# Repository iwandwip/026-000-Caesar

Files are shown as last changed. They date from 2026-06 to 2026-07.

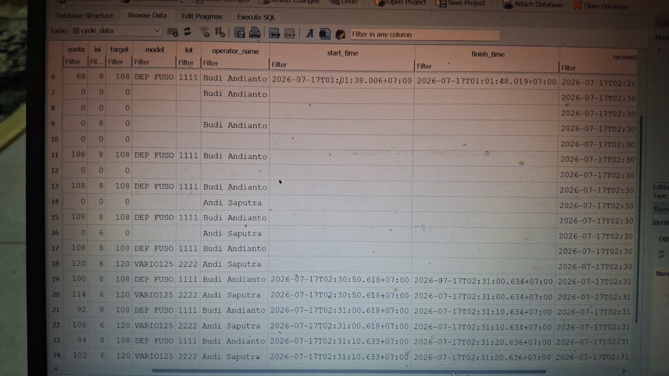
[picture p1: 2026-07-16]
docs/2.jpeg

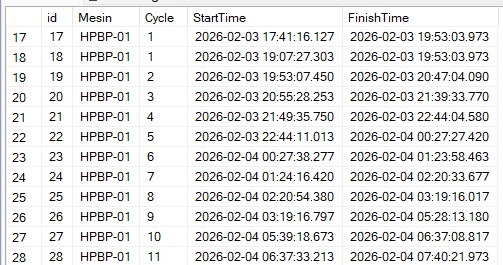
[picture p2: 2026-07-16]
docs/1.jpeg

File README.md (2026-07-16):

# Caesar Control System

Caesar is an ESP32 control project for a two-side production process. It combines a Nextion HMI, a GM66 barcode scanner, and a DS3231 RTC. The firmware owns validation and process state; the HMI presents data and sends user actions.

## Repository Layout

```text
026-000-Caesar/
├── firmware/                         ESP32 firmware, local Arduino libraries, and setup notes
│   ├── CaesarFirmwareV1/             Main Arduino sketch
│   └── README.md                     Firmware architecture, wiring, and HMI contract
├── HMI/                              Versioned Nextion .HMI source files
├── nextion/                          HMI file used by extractor and extracted source views
│   ├── HMI CAESAR_15.HMI             Current extraction input
│   ├── Nextion2Text/                 Nextion2Text checkout
│   └── output/                       Extracted text and JSON per HMI revision
├── src/                              HMI extraction scripts
├── pcb/                              PCB design archive and extracted design files
├── assets/                           Manual, work instruction, and reference documents
├── docs/                             Design specifications and implementation plans
└── README.md
```

`HMI/` stores HMI revision history. Copy the revision you want to inspect into `nextion/` before running the extractor. The current extractor input is `nextion/HMI CAESAR_15.HMI`.

## System Overview

| Component | Responsibility |
| --- | --- |
| ESP32 | Validates operators, moulds, lots, downtime state, scanner input, and RTC data. |
| Nextion HMI | Displays process state, accepts manual input, and sends page and button events. |
| GM66 scanner | Sends barcode data to ESP32 through `Serial2`. |
| DS3231 RTC | Supplies timestamps for `pageSys.tNow` and downtime start records. |

The firmware stores shared process state in `pageSys` on the HMI. Firmware callbacks validate process actions.

See [`firmware/README.md`](firmware/README.md) for wiring, firmware modules, supported input flows, and HMI integration requirements.

## Windows Setup

Use this sequence after cloning on a Windows laptop.

```powershell
git clone <repository-url>
cd 026-000-Caesar
npm install
```

Install Arduino IDE, add the ESP32 board package, then open `firmware/CaesarFirmwareV1/CaesarFirmwareV1.ino`. Install or expose the libraries under `firmware/libraries/` to your Arduino environment before compiling.

Set the WiFi network for the target site in `firmware/CaesarFirmwareV1/config.h`:

```cpp
#define WIFI_SSID "your-wifi-name"
#define WIFI_PASS "your-wifi-password"
```

The firmware and tools use HiveMQ public MQTT. Each deployed machine needs its own `MQTT_ADDR`. Update the same address in these files before running multiple machines:

```text
firmware/CaesarFirmwareV1/config.h
tools/mqtt-simulator.js
tools/mqtt-debug-subscriber.js
tools/node-red-simulator-flow.json
tools/node-red-debug-subscriber-flow.json
```

Flash the ESP32 after configuring WiFi and the address.

## MQTT Tools

Install Node.js LTS, then run `npm install` from repository root.

```powershell
# Terminal 1: simulated machine publishes START and finish events.
npm run mqtt:simulate

# Terminal 2: receives firmware dataA/dataB messages and writes SQLite rows.
npm run mqtt:debug
```

The simulator sends `START`, waits 10 seconds, then sends a `1cycle` event with `startTime` and `finishTime`. Firmware counts the event when both interlocks are ready. It publishes retained Front and Back state after each accepted cycle and process-state change.

`mqtt:debug` creates `data/caesar.db` in the repository. Set `CAESAR_DB_PATH` when you need another database location:

```powershell
$env:CAESAR_DB_PATH = "D:\CaesarData\caesar.db"
npm run mqtt:debug
```

Use [DB Browser for SQLite](https://sqlitebrowser.org/) to inspect table `cycle_data`.

### Node-RED Option

Use Node-RED instead of either JavaScript process when you want a visual flow.

```powershell
# Run once if node-red is not installed.
npm install -g --unsafe-perm node-red

# First run creates the Node-RED user directory.
node-red

# Stop Node-RED, then install the SQLite node.
cd $env:USERPROFILE\.node-red
npm install node-red-node-sqlite

# Create the shared SQLite directory once.
New-Item -ItemType Directory -Force C:\sqlite-data
```

Import `tools/node-red-simulator-flow.json` for the machine simulator. Import `tools/node-red-debug-subscriber-flow.json` for the subscriber and SQLite writer. Deploy both flows after import. The debug flow writes `C:\sqlite-data\caesar.db` for every Windows user. If Windows denies directory creation, create `C:\sqlite-data` once from an elevated PowerShell session.

Run one simulator only: JavaScript or Node-RED. Running both publishes duplicate finish events and doubles cycle counts.

## HMI Extraction

The extraction workflow converts a Nextion `.HMI` file into text and JSON for review, Git diffs, and firmware work. It only reads `.HMI` files. It cannot rebuild an `.HMI` file from extracted output.

### Requirements

- Linux shell or Bash
- Git
- Python 3.8 or newer
- A `.HMI` file directly inside `nextion/`

Check Python:

```bash
python3 --version
```

Create a virtual environment when needed:

```bash
python3 -m venv .venv
source .venv/bin/activate
```

The extraction scripts use Python standard-library modules only.

### Run Extraction

From repository root:

```bash
./src/nextion2text.sh
```

The script:

1. Finds `.HMI` and `.hmi` files directly under `nextion/`.
2. Clones [Nextion2Text](https://github.com/MMMZZZZ/Nextion2Text) into `nextion/Nextion2Text/` when absent.
3. Replaces previous output for each processed HMI file.
4. Writes text and JSON output to `nextion/output/<hmi-name>/`.

For `nextion/HMI CAESAR_15.HMI`, output appears under:

```text
nextion/output/HMI_CAESAR_15/
├── text/
└── json/
```

The script calls Nextion2Text with:

```bash
-e -s -j -p visual
```

| Flag | Purpose |
| --- | --- |
| `-e` | Includes empty events. |
| `-s` | Produces page, component, and event statistics. |
| `-j` | Produces JSON output. |
| `-p visual` | Includes visual properties such as coordinates, colors, fonts, and images. |

### Linux `ansi` Codec Error

Nextion2Text requests the Windows `ansi` codec. Linux Python does not provide that name. `src/run_nextion2text.py` registers `ansi` as `latin-1` before it starts Nextion2Text.

Run `./src/nextion2text.sh`; do not run `Nextion2Text.py` directly on Linux.

### Common Errors

`ERROR: no .HMI files found` means no `.HMI` file exists directly in `nextion/`. Copy the desired source file from `HMI/` first.

```bash
cp "HMI/HMI CAESAR_15.HMI" "nextion/HMI CAESAR_15.HMI"
./src/nextion2text.sh
```

If the script lacks execute permission:

```bash
chmod +x src/nextion2text.sh
```

## Project Documents

- `assets/MANUAL BOOK_CAESAR.docx`: Caesar manual.
- `assets/WORK INSTRUCTION_CAESAR.pdf`: work instruction.
- `assets/SKRIPSI_CAESAR.docx`: project thesis.
- `pcb/`: PCB source archive and extracted project files.

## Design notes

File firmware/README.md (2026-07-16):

# Caesar ESP32 Firmware

`CaesarFirmwareV1` runs on ESP32 and controls Nextion process state, a GM66 scanner, and a DS3231 RTC. The firmware validates all operator, mould, lot, and downtime actions. The HMI displays values and reports page or button events.

Open `firmware/CaesarFirmwareV1/CaesarFirmwareV1.ino` in Arduino IDE or your ESP32 Arduino build environment.

## Source Files

| File | Responsibility |
| --- | --- |
| `CaesarFirmwareV1.ino` | Page and component declarations, setup, main loop, and callback registration. |
| `config.h` | Serial settings and static operator, mould, and lot lookup tables. |
| `login.ino` | Front and back operator login, logout, and page tracking. |
| `input.ino` | Mould and lot input, validation, clearing, and raw Nextion value reads. |
| `scanner.ino` | GM66 receive buffer and page-specific scanner routing. |
| `downtime.ino` | Front, back, and machine downtime state transitions. |
| `rtc.ino` | DS3231 initialization and one-second HMI time updates. |
| `dashboard.ino` | Dashboard status, readiness, and interlock display synchronization. |
| `simulation.ino` | Front and back auto-cycle controls on `pageSim`. |
| `cycle.ino` | MQTT finish-event validation and Front/Back cycle mutation. |
| `wifi_mqtt.ino` | WiFi connection, MQTT reconnect, subscriptions, and command dispatch. |
| `publish.ino` | Retained MQTT JSON for Front and Back process state. |

## Dependencies

The repository includes local Arduino libraries under `firmware/libraries/`.

- ESP32 Arduino core
- ITEADLIB Arduino Nextion library
- Adafruit RTClib
- Adafruit BusIO
- ArduinoJson 7
- PubSubClient

Select the ESP32 board that matches the deployed hardware. The repository does not contain an Arduino CLI configuration or a pinned board package version.

## Wiring and Serial Ports

### Nextion HMI

The ITEAD library uses ESP32 `Serial` for Nextion traffic:

```cpp
// firmware/libraries/ITEADLIB_Arduino_Nextion/NexConfig.h
#define nexSerial Serial
```

Nextion Editor Debug and the deployed display share this serial channel. Do not open Arduino Serial Monitor on the same USB serial port while Nextion Editor Debug is connected. ITEAD debug output stays disabled because it would corrupt Nextion protocol frames.

### GM66 Scanner

`config.h` configures the scanner on ESP32 `Serial2`.

```cpp
#define SCANNER_SERIAL Serial2
#define SCANNER_RX_PIN 16
#define SCANNER_TX_PIN 17
#define SCANNER_BAUD 9600
```

| GM66 wire | ESP32 connection |
| --- | --- |
| TX | GPIO16, Serial2 RX |
| RX | GPIO17, Serial2 TX |
| VCC | 5V |
| GND | GND |

The scanner uses `9600`, `SERIAL_8N1`.

### DS3231 RTC

`rtc.ino` uses `Wire.begin()`, which uses ESP32 default I2C pins unless the board setup overrides them.

| DS3231 signal | Default ESP32 pin |
| --- | --- |
| SDA | GPIO21 |
| SCL | GPIO22 |

The firmware reads time once each second and writes `YYYY-MM-DD HH:MM:SS` to `pageSys.tNow.txt`. If the RTC lost power, firmware initializes it with compile time. Set the RTC to production time before deployment.

## Nextion Page IDs

Page IDs follow page order in Nextion Editor. Firmware declarations must match this mapping.

| ID | Page |
| --- | --- |
| 0 | `pageDashboard` |
| 1 | `pageLoginF` |
| 2 | `pageLoginB` |
| 3 | `pageMldF` |
| 4 | `pageMldB` |
| 5 | `pageLotF` |
| 6 | `pageLotB` |
| 7 | `pageOutputNG` |
| 8 | `pageInputNGF` |
| 9 | `pageInputNGB` |
| 10 | `pageDtF` |
| 11 | `pageDtB` |
| 12 | `pageDtInfoF` |
| 13 | `pageDtInfoB` |
| 14 | `pageDtMc` |
| 15 | `pageDtMcInfo` |
| 16 | `pageSim` |
| 17 | `pageSys` |
| 18 | `keybdA` |
| 19 | `keybdB` |

Each page sends a page notification through its Preinitialize event. Example for the dashboard:

```text
printh 65 00 00 00 FF FF FF
```

Use the page ID in the third byte. `pageCallback()` updates `currentPageId`, which controls where scanner data is written.

## Process Data

`config.h` contains the current static lookup tables.

| Code | Operator | Mould | Cavity | Lot model | Target |
| --- | --- | --- | ---: | --- | ---: |
| `1111` | Budi Andianto | MOULD A | 8 | DEP FUSO | 108 |
| `2222` | Andi Saputra | MOULD B | 6 | VARIO125 | 120 |
| `3333` | Siti Nurhaliza | MOULD C | 4 | GENIO | 96 |

Change these tables in `config.h` when production master data changes.

## WiFi and MQTT

Set site WiFi credentials and the machine address in `config.h` before flashing:

```cpp
#define WIFI_SSID "your-wifi-name"
#define WIFI_PASS "your-wifi-password"
#define MQTT_ADDR "unique-machine-address"
```

The current broker is `broker.hivemq.com:1883`. Each machine address must be unique on the public broker.

| Topic | Direction | Payload |
| --- | --- | --- |
| `start/IOTHP-BP/<addr>` | Simulator to server | `START` |
| `finish/IOTHP-BP/<addr>` | Simulator to ESP32 | JSON `1cycle` event with timestamps |
| `CONTROL/IOTHP-BP/<addr>` | Server to ESP32 | `REBOOT` |
| `dataA/IOTHP-BP/<addr>` | ESP32 to server | Retained Front state JSON |
| `dataB/IOTHP-BP/<addr>` | ESP32 to server | Retained Back state JSON |

The firmware accepts a finish event only when its payload has this shape:

```json
{
  "event": "1cycle",
  "startTime": "2026-07-16T07:00:00.000Z",
  "finishTime": "2026-07-16T07:00:10.000Z"
}
```

Firmware ignores the event when either side is not ready, quota cannot cover isi, or required HMI state cannot be read. A valid event increments both layer cycles, updates output and quota, then publishes retained state.

Each `dataA` and `dataB` message contains:

```json
{
  "cycle": 42,
  "output": 336,
  "ok": 330,
  "ng": 6,
  "quota": 72,
  "isi": 8,
  "target": 108,
  "model": "DEP FUSO",
  "lot": "1111",
  "operator": "Budi Andianto",
  "startTime": "2026-07-16T07:00:00.000Z",
  "finishTime": "2026-07-16T07:00:10.000Z"
}
```

Firmware also publishes after valid mould or lot changes, clears, login, and logout. These state-only messages keep the last accepted cycle timestamps.

See the root [MQTT tools section](../README.md#mqtt-tools) for JavaScript and Node-RED simulator, subscriber, and SQLite setup.

## Login Flow

1. Open `pageLoginF` or `pageLoginB`.
2. Scan an operator barcode or enter an ID manually.
3. Press OK.
4. Firmware validates `OPERATORS[]`, writes the operator data to `pageSys`, and displays the operator name.

Invalid IDs display `ID SALAH`.

## Mould and Lot Flow

Scanner and manual keyboard input follow the same model: fill a field, then press OK. Firmware owns the validation and save action.

### Mould

On `pageMldF` and `pageMldB`, a valid code writes the mould code, model, cavity, and default isi values to `pageSys`. Firmware also initializes `pageLotF.nIsiLotF` or `pageLotB.nIsiLotB` from the cavity count.

### Lot

On `pageLotF` and `pageLotB`, a valid lot requires a mould on the same side. Firmware reads cavity and isi through raw Nextion number responses, then rejects these conditions:

| Condition | HMI message |
| --- | --- |
| Unknown lot code | `LOT NG` |
| Cavity read failure | `CAV READ NG` |
| Isi read failure | `ISI READ NG` |
| No validated mould | `NO MOULD` |
| Isi is zero | `ISI 0` |
| Isi exceeds cavity | `ISI > CAV` |

Keyboard edits to lot isi remain in the lot page. Returning from a keyboard page does not overwrite the value.

`readNextionText()` and `readNextionValue()` in `input.ino` read `0x70` text and `0x71` numeric response frames directly. They avoid the ITEAD library response parser when delayed serial frames would produce an empty or stale result.

## Scanner Routing

Scanner input routes by `currentPageId`:

| Page | Scanner action |
| --- | --- |
| `pageLoginF` | Writes front operator ID. |
| `pageLoginB` | Writes back operator ID. |
| `pageMldF` | Fills front mould code. |
| `pageMldB` | Fills back mould code. |
| `pageLotF` | Fills front lot code and loads cavity as default isi. |
| `pageLotB` | Fills back lot code and loads cavity as default isi. |

The scanner does not auto-confirm a value. The operator presses OK after each scan.

## Downtime Flow

Downtime buttons update `pageSys`, lock machine readiness, and show a matching information page.

| Selection page | Shared state | Information page |
| --- | --- | --- |
| `pageDtF` | `nFDtAct`, `tFDtType`, `tFDtStart` | `pageDtInfoF` |
| `pageDtB` | `nBDtAct`, `tBDtType`, `tBDtStart` | `pageDtInfoB` |
| `pageDtMc` | `nMDtAct`, `tMDtType`, `tMDtStart` | `pageDtMcInfo` |

After a reason is selected, firmware uses this route:

```text
pageDtF / pageDtB / pageDtMc
  -> pageDashboard
  -> matching downtime information page
```

`showDowntimeInfo()` waits 100 ms after loading `pageDashboard`, then opens the matching information page. The info page Postinitialize event copies downtime type and start time from `pageSys`.

RUNNING clears the matching downtime state and returns to `pageDashboard`.

## HMI Integration Rules

- Keep `Send Component ID: on release` enabled for firmware-managed buttons.
- Keep the page Preinitialize notifications aligned with the page ID table.
- Remove inline Touch Release logic from firmware-managed mould, lot, and downtime buttons. Firmware callbacks own these transitions.
- Keep Back button behavior only where it remains HMI navigation. Firmware handles state changes and validation.
- Do not add lot-page Postinitialize code that copies `pageSys.nFIsi` or `pageSys.nBIsi` into lot isi fields. That code would overwrite keyboard edits.

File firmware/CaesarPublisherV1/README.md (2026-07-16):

# CaesarPublisherV1

Hardware simulator untuk CaesarFirmwareV1. ESP32 ini mensimulasikan siklus mesin cetak tanpa mesin asli. Operator tekan tombol di sensor, firmware kirim sinyal START dan siklus selesai ke broker MQTT yang sama dengan simulator software.

## Perbedaan dengan Firmware Utama

| Aspek | CaesarFirmwareV1 | CaesarPublisherV1 |
|---|---|---|
| Fungsi | Kontrol mesin cetak asli | Simulasi siklus via sensor |
| HMI Nextion | Ya | Tidak |
| Barcode scanner | Ya | Tidak |
| Quota/ISI tracking | Ya | Tidak |
| Operator/Mould/Lot | Ya | Tidak |
| Interlock GPIO25 | Ya | Tidak |
| MQTT finish topic | Sama | Sama |
| MQTT broker | Sama | Sama |

PublisherV1 mengirim data ke topik yang sama dengan simulator software (`start/...` dan `finish/...`). CaesarFirmwareV1 tidak tahu bedanya. Data dari hardware atau software sama saja.

## Cara Kerja

```
Operator tekan sensor
       │
       ▼
┌──────────────┐
│  ESP32       │
│  PublisherV1 │
└──────┬───────┘
       │
       ▼
  start/IOTHP-BP/...  →  "START"
       │
       ▼
  Operator tekan up/down 5x
       │
       ▼
  finish/IOTHP-BP/... →  {"event":"1cycle","startTime":"...","finishTime":"..."}
```

## Sensor

| Sensor | Pin | Fungsi |
|---|-----|---|
| Front (depan) | GPIO32 | Mulai siklus layer depan |
| Back (belakang) | GPIO35 | Mulai siklus layer belakang |
| Up (naik) | GPIO33 | Gerakan naik (step 1, 3, 5) |
| Down (turun) | GPIO25 | Gerakan turun (step 2, 4) |
| WiFi LED | GPIO26 | Indikator koneksi WiFi |

---

## File

### config.h

Pengaturan utama. Semua bisa diubah tanpa menyentuh kode program.

| Define | Value | Fungsi |
|---|---|---|
| WIFI_SSID | TIMEO | SSID WiFi |
| WIFI_PASS | 1234Saja | Password WiFi |
| MQTT_SERVER | broker.hivemq.com | Broker MQTT |
| MQTT_PORT | 1883 | Port broker |
| MQTT_ADDR | 91c21b8614cd | ID device |
| MQTT_CLIENT_ID | CaesarPublisher/91c21b8614cd | Client ID MQTT |
| START_TOPIC | start/IOTHP-BP/91c21b8614cd | Topik sinyal START |
| FINISH_TOPIC | finish/IOTHP-BP/91c21b8614cd | Topik siklus selesai |
| CONTROL_TOPIC | CONTROL/IOTHP-BP/91c21b8614cd | Topik perintah |
| NTP_SERVER | pool.ntp.org | Server waktu |
| WIB_TIMEZONE | WIB-7 | Zona waktu |
| FRONT_PIN | GPIO32 | Sensor depan |
| BACK_PIN | GPIO35 | Sensor belakang |
| UP_PIN | GPIO33 | Sensor naik |
| DOWN_PIN | GPIO25 | Sensor turun |
| WIFI_LED_PIN | GPIO26 | LED WiFi |
| OTA_USERNAME | admin | Username update firmware |
| OTA_PASSWORD | 123654789 | Password update firmware |

---

### CaesarPublisherV1.ino

File utama yang menghubungkan semua bagian. Berisi objek global dan alur utama program.

**Objek global:**
- `WiFiClient wifiClient` — objek koneksi WiFi
- `PubSubClient mqttClient(wifiClient)` — objek koneksi MQTT
- `WebServer httpServer(80)` — web server di port 80 untuk OTA update
- `ESP32HTTPUpdateServer httpUpdater` — handler halaman web update firmware

**`setup()`** — dijalankan sekali saat ESP32 dinyalakan:
1. `Serial.begin(115200)` — nyalakan serial monitor untuk debug
2. `pinMode(FRONT_PIN, INPUT)` — set GPIO32 sebagai input (sensor depan)
3. `pinMode(BACK_PIN, INPUT)` — set GPIO35 sebagai input (sensor belakang)
4. `pinMode(UP_PIN, INPUT)` — set GPIO33 sebagai input (sensor naik)
5. `pinMode(DOWN_PIN, INPUT)` — set GPIO25 sebagai input (sensor turun)
6. `pinMode(WIFI_LED_PIN, OUTPUT)` — set GPIO26 sebagai output (LED WiFi)
7. `digitalWrite(WIFI_LED_PIN, LOW)` — matikan LED saat awal
8. `initCycleInputs()` — baca posisi awal semua sensor agar tidak false trigger
9. `initTime()` — set zona waktu WIB sebelum NTP jalan
10. `setupWifi()` — mulai koneksi WiFi
11. `setupMqtt()` — set alamat broker dan callback
12. `httpUpdater.setup(...)` — daftarkan halaman web update firmware di `/update`
13. `httpServer.begin()` — nyalakan web server di port 80

**`loop()`** — dijalankan ratusan kali per detik:
1. `mqttLoop()` — proses WiFi reconnect, MQTT reconnect, dan pesan masuk
2. `syncTime()` — ambil waktu dari internet jika belum sinkron
3. `httpServer.handleClient()` — handle request dari browser (untuk OTA update)
4. `updateCycleInputs()` — baca semua sensor, proses logika siklus

---

### wifi_mqtt.ino

Mengatur koneksi WiFi dan MQTT. Semua komunikasi dengan server melewati file ini.

**Variabel global:**
- `lastWifiAttempt` — timestamp kapan terakhir coba sambung WiFi. Digunakan untuk delay 5 detik agar ESP32 tidak spam reconnect.
- `lastMqttAttempt` — timestamp kapan terakhir coba sambung MQTT. Delay sama, 5 detik.

**`mqttCallback(topic, payload, length)`** — handler saat terima pesan dari server. Dipanggil otomatis oleh PubSubClient saat ada pesan masuk. Cek dua kondisi:
1. Pesan datang dari `CONTROL_TOPIC` DAN isinya `REBOOT` (6 karakter) → restart ESP32 via `ESP.restart()`
2. Selain itu → diabaikan

PublisherV1 hanya menerima satu jenis pesan: perintah reboot.

**`setupWifi()`** — mulai koneksi WiFi:
1. `WiFi.mode(WIFI_STA)` — set mode station (bukan access point)
2. `WiFi.setHostname(MQTT_CLIENT_ID)` — set nama device di jaringan
3. `WiFi.begin(WIFI_SSID, WIFI_PASS)` — mulai koneksi
4. `lastWifiAttempt = millis()` — catat waktu percobaan

**`setupMqtt()`** — konfigurasi MQTT:
1. `mqttClient.setServer(MQTT_SERVER, MQTT_PORT)` — set alamat broker
2. `mqttClient.setCallback(mqttCallback)` — daftarkan handler pesan masuk
3. `mqttClient.setBufferSize(256)` — buffer untuk payload (cukup untuk JSON siklus)
4. `mqttClient.setKeepAlive(60)` — jika tidak ada aktivitas 60 detik, koneksi putus

**`reconnectWifi()`** — auto-reconnect WiFi:
1. Jika WiFi sudah terhubung → skip
2. Jika belum dan sudah lewat 5 detik sejak percobaan terakhir → putuskan WiFi, sambung ulang
3. Delay 5 detik mencegah ESP32 mencoba sambung ulang terlalu sering

**`reconnectMqtt()`** — auto-reconnect MQTT:
1. Jika MQTT sudah terhubung → skip
2. Jika belum dan sudah lewat 5 detik → coba `mqttClient.connect()`
3. Setelah terhubung → subscribe `CONTROL_TOPIC` agar bisa terima perintah REBOOT

**`mqttLoop()`** — fungsi utama yang dipanggil dari `loop()`:
1. `reconnectWifi()` — coba sambung WiFi jika perlu
2. `digitalWrite(WIFI_LED_PIN, ...)` — nyalakan LED jika WiFi terhubung, matikan jika tidak
3. Jika WiFi belum terhubung → skip (tidak bisa proses MQTT tanpa WiFi)
4. `reconnectMqtt()` — coba sambung MQTT jika perlu
5. Jika MQTT terhubung → `mqttLoop()` untuk proses pesan masuk

---

### time.ino

Pengambilan waktu dari internet (NTP). Waktu digunakan untuk timestamp di payload siklus.

**Variabel global:**
- `ntpConfigured` — apakah sudah pernah jalankan `configTzTime()`. Cukup sekali.
- `ntpReady` — apakah waktu dari NTP sudah berhasil diambil
- `lastNtpAttempt` — kapan terakhir coba ambil waktu
- `NTP_RETRY_INTERVAL` — interval retry 1 detik

**`initTime()`** — panggilan sekali saat `setup()`:
1. `setenv("TZ", WIB_TIMEZONE, 1)` — set variabel environment zona waktu ke "WIB-7"
2. `tzset()` — beritahu sistem bahwa semua waktu harus dikonversi ke WIB

Tidak perlu internet untuk fungsi ini. Waktu belum tersedia — hanya zona waktu yang diatur.

**`syncTime()`** — sinkronisasi waktu dari NTP. Dipanggil terus-menerus dari `loop()`:
1. Jika waktu sudah ready → skip (sudah sinkron)
2. Jika WiFi belum terhubung → skip (butuh internet)
3. Jika belum lewat 1 detik sejak percobaan terakhir → skip (delay)
4. Jalankan `configTzTime(WIB_TIMEZONE, NTP_SERVER)` sekali pertama
5. Coba ambil waktu dari server via `getLocalTime()`
6. Jika berhasil → `ntpReady = true`

Setelah `ntpReady = true`, waktu tersedia untuk semua fungsi yang membutuhkan timestamp.

**`getTimestamp(buffer, length)`** — ambil waktu saat ini dan format ke ISO8601 WIB:
1. Jika NTP belum ready → return `false`
2. Ambil waktu dari sistem via `getLocalTime()`
3. Format ke string: `YYYY-MM-DDTHH:MM:SS.000+07:00`
4. Return `true` jika berhasil

Contoh output: `2026-07-17T14:30:00.000+07:00`

Waktu tidak tersedia sampai WiFi terhubung dan NTP sinkron (biasanya 2-5 detik setelah WiFi nyambung).

---

### cycle.ino

Logika siklus dari sensor. File ini menentukan kapan siklus dimulai, bagaimana menghitung gerakan, dan kapan siklus selesai.

**Variabel state:**
- `frontLatched` / `backLatched` / `upLatched` / `downLatched` — posisi terakhir tiap sensor. Digunakan untuk mendeteksi tepi naik (sensor baru saja ditekan, bukan sedang ditekan terus).
- `cycleStarted` — apakah siklus sedang berjalan
- `expectUp` — gerakan selanjutnya harus up (mencegah double count)
- `stepCount` — jumlah gerakan valid yang terhitung
- `cycleStartTime` — waktu saat siklus dimulai (dari NTP)

**`initCycleInputs()`** — panggilan sekali saat `setup()`:
Baca posisi awal semua sensor. Tanpa ini, jika sensor sudah ditekan saat ESP32 nyala, firmware akan false trigger siklus baru di detik pertama.

**`publishStart()`** — kirim sinyal START ke broker:
1. Cek MQTT connected. Jika tidak → skip.
2. Publish `"START"` tanpa retained ke `START_TOPIC`
3. Pesan ini memberitahu CaesarFirmwareV1 bahwa siklus baru dimulai

**`publishCycle()`** — kirim JSON siklus selesai:
1. Cek MQTT connected. Jika tidak → skip.
2. Ambil waktu sekarang dari NTP via `getTimestamp()`
3. Buat JSON: `{"event":"1cycle","startTime":"...","finishTime":"..."}`
4. `startTime` = waktu saat siklus dimulai (dari `cycleStartTime`)
5. `finishTime` = waktu saat ini (waktu siklus selesai)
6. Publish tanpa retained ke `FINISH_TOPIC`

CaesarFirmwareV1 terima JSON ini → increment siklus, kurangi kuota, update layar, kirim data ke server.

**`startCycle()`** — mulai siklus baru:
1. Jika siklus sudah berjalan (`cycleStarted == true`) → skip (tidak mulai siklus baru sebelum yang sebelumnya selesai)
2. Ambil waktu dari NTP. Jika gagal → skip (timestamp tidak tersedia)
3. Set `cycleStarted = true`
4. Reset `stepCount = 0`
5. Set `expectUp = true` (gerakan pertama harus up)
6. Simpan waktu mulai ke `cycleStartTime`
7. `publishStart()` — kirim sinyal START

**`finishCycle()`** — selesaikan siklus:
1. `publishCycle()` — kirim JSON siklus selesai
2. Set `cycleStarted = false`
3. Reset `stepCount = 0`
4. Set `expectUp = true`

**`updateCycleInputs()`** — fungsi utama yang dipanggil dari `loop()`. Membaca semua sensor dan memproses logika siklus:

1. Baca posisi semua sensor: `digitalRead(FRONT_PIN) == LOW` artinya sensor ditekan
2. Deteksi tepi naik: sensor baru saja ditekan (belum ditekan sebelumnya)
   - `frontPressed && !frontLatched` → sensor depan baru ditekan
   - `backPressed && !backLatched` → sensor belakang baru ditekan
3. Jika Front/Back baru ditekan → `startCycle()`
4. Deteksi gerakan up: sensor up ditekan, sebelumnya tidak, `expectUp == true`, dan siklus berjalan
   - `stepCount++`, `expectUp = false`
5. Deteksi gerakan down: sensor down ditekan, sebelumnya tidak, `expectUp == false`, dan siklus berjalan
   - `stepCount++`, `expectUp = true`
6. Update posisi terakhir semua sensor (untuk deteksi tepi di loop berikutnya)
7. Jika `stepCount >= 5` dan siklus berjalan → `finishCycle()`

**Pola gerakan:**
```
Sensor Front/Back ditekan → START
Up   (step 1) → expectUp = false
Down (step 2) → expectUp = true
Up   (step 3) → expectUp = false
Down (step 4) → expectUp = true
Up   (step 5) → FINISH
```

Total 5 gerakan: 3 up + 2 down (atau 2 up + 3 down, tergantung urutan awal).

---

## Topik MQTT

| Topik | Arah | Isi |
|---|---|-----|
| `start/IOTHP-BP/91c21b8614cd` | Publisher → Broker | `"START"` |
| `finish/IOTHP-BP/91c21b8614cd` | Publisher → Broker | JSON siklus |
| `CONTROL/IOTHP-BP/91c21b8614cd` | Broker → Publisher | `"REBOOT"` |

## OTA Update

Akses `http://[IP_ESP32]/update` dari browser. Login:
- Username: `admin`
- Password: `123654789`

Upload file `.bin` firmware baru dari browser. ESP32 akan restart otomatis setelah upload selesai.

## Troubleshooting

| Masalah | Solusi |
|---|---|
| LED WiFi mati | WiFi tidak terhubung. Cek SSID dan password di `config.h` |
| Siklus tidak mulai | Pastikan sensor Front/Back ditekan dulu |
| Siklus tidak selesai | Hitung 5 gerakan: up, down, up, down, up |
| Data tidak sampai ke firmware | Cek koneksi internet, pastikan broker.hivemq.com:1883 bisa diakses |
| Waktu salah di payload | NTP belum sinkron. Tunggu beberapa detik setelah WiFi terhubung |

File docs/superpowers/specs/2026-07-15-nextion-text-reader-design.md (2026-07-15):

# Nextion Text Reader Design

## Goal

Read mould and lot text inputs reliably on ESP32. `NexText::getText()` currently returns an empty string, causing valid codes to display `MOULD NG` or `LOT NG`.

## Scope

Add one firmware-local helper in `firmware/CaesarFirmwareV1/input.ino`. Replace four failing `NexText::getText()` calls:

- `tInMF` in front mould validation
- `tInMB` in back mould validation
- `tInLotF` in front lot validation
- `tInLotB` in back lot validation

No HMI, scanner, login, or ITEADLIB changes.

## Design

`readNextionText(component, buffer, bufferSize)` sends `get <component>.txt` through `sendCommand()`. It reads from `nexSerial` until timeout and accepts only a Nextion string response:

```
0x70 <text bytes> 0xFF 0xFF 0xFF
```

The helper excludes byte `0x70` and response terminator from output. It null-terminates output, bounds writes to `bufferSize - 1`, and returns `true` only after complete string response. Timeout, malformed response, or an empty string return `false`.

Before command, helper drains stale Nextion serial bytes. It runs only from OK-button callbacks after `nexLoop()` has dispatched touch event, so command response owns serial stream.

## Call Flow

1. User types or scans code into existing Text input.
2. User presses OK.
3. Callback invokes `readNextionText()` for field component name.
4. On read failure, existing lookup receives empty string and preserves existing `MOULD NG` or `LOT NG` behavior.
5. On valid read, existing `findMould()` or `findLot()` lookup and page-system updates remain unchanged.

## Error Handling

- Timeout: output is empty; validation reports existing NG status.
- Empty Nextion text: output is empty; validation reports existing NG status.
- Oversized text: helper truncates safely, drains response terminator, then returns completed response. Lookup only succeeds if truncated value matches a configured code.
- Non-string response: discard bytes and return failure after timeout.

## Verification

- Run `git diff --check`.
- Compile if Arduino CLI becomes available.
- On hardware/HMI simulator, enter or scan `1111` on front/back mould and lot pages, press OK, and confirm existing model/cavity/target fields populate.
- Confirm an unknown code still shows `MOULD NG` or `LOT NG`.

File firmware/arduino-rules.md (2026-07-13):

# Arduino .ino Programming Rules

> Comprehensive guide to Arduino IDE preprocessing, file structure, and best practices

## Table of Contents
- [File Structure Requirements](#file-structure-requirements)
- [Preprocessing Pipeline](#preprocessing-pipeline)
- [Library Detection & Inclusion](#library-detection--inclusion)
- [Variable Scope & Access](#variable-scope--access)
- [Function Declaration Rules](#function-declaration-rules)
- [File Type Handling](#file-type-handling)
- [Common Pitfalls](#common-pitfalls)
- [Best Practices](#best-practices)
- [Examples](#examples)

---

## File Structure Requirements

### Rule 1: Folder Name Must Match Main File Name

**REQUIRED STRUCTURE:**
```
MyProject/              ← Folder name
├── MyProject.ino       ← Main file (MUST match folder name)
├── other_file.ino      ← Additional .ino files (optional)
├── MyClass.h           ← Header files (optional)
└── MyClass.cpp         ← C++ files (optional)
```

**❌ INVALID:**
```
MyProject/
└── sketch.ino          ❌ Name mismatch - Arduino IDE will refuse to open
```

### Rule 2: All .ino Files Must Be in Single Folder

**For .ino files:**
```
✅ VALID:
MyProject/
├── MyProject.ino
├── functions.ino
└── utils.ino

❌ INVALID:
MyProject/
├── MyProject.ino
└── src/
    └── functions.ino   ❌ .ino files cannot be in subfolders
```

**For .cpp/.h files:**
```
✅ VALID - Can use subfolders:
MyProject/
├── MyProject.ino
└── src/
    ├── MyClass.h       ✅ .h/.cpp can be in subfolders
    └── MyClass.cpp
```

### Rule 3: Main File is Entry Point

The file matching the folder name is **always processed first**, regardless of alphabetical order.

**Processing Order:**
```
MyProject/
├── MyProject.ino       ← 1. ALWAYS FIRST
├── aaa_config.ino      ← 2. Then alphabetically
├── bbb_sensors.ino     ← 3. Then alphabetically
└── zzz_utils.ino       ← 4. Last alphabetically
```

---

## Preprocessing Pipeline

### Stage 1: File Concatenation

All `.ino` files in the sketch folder are concatenated into a single `.cpp` file.

**Input:**
```
MyProject/
├── MyProject.ino
├── functions.ino
└── utils.ino
```

**Output (internal):**
```cpp
// Contents of MyProject.ino
// Contents of functions.ino
// Contents of utils.ino
```

### Stage 2: Add Arduino.h Include

If not already present, `#include <Arduino.h>` is automatically added at the top.

**Before:**
```cpp
void setup() {
  Serial.begin(9600);
}
```

**After preprocessing:**
```cpp
#include <Arduino.h>

void setup() {
  Serial.begin(9600);
}
```

### Stage 3: Generate Function Prototypes

Arduino IDE scans for all function definitions and creates forward declarations.

**Before:**
```cpp
void setup() {
  myFunction();  // Can call before definition!
}

void myFunction() {
  Serial.println("Hello");
}
```

**After preprocessing:**
```cpp
#include <Arduino.h>

// Auto-generated prototypes
void setup();
void myFunction();

void setup() {
  myFunction();
}

void myFunction() {
  Serial.println("Hello");
}
```

### Stage 4: Add #line Directives

`#line` directives maintain accurate line numbers in error messages, so errors reference your original `.ino` file lines.

### Stage 5: Generate main() Function

Arduino automatically wraps your code with a `main()` function.

**Your code:**
```cpp
void setup() {
  // init code
}

void loop() {
  // main code
}
```

**Generated internally:**
```cpp
int main(void) {
  init();        // Arduino initialization
  setup();
  
  while(true) {
    loop();
  }
  
  return 0;
}
```

---

## Library Detection & Inclusion

### Rule 4: Library Includes Must Be in .ino Files

Arduino IDE **only scans .ino files** for library detection.

**✅ CORRECT - Include in .ino file:**
```cpp
// MyProject.ino
#include <Wire.h>
#include <SPI.h>
#include "MyClass.h"

void setup() {
  Wire.begin();
}
```

**❌ WRONG - Include only in .cpp:**
```cpp
// MyProject.ino
void setup() {
  Wire.begin();  // Wire library might not be linked!
}

// MyClass.cpp
#include <Wire.h>  // ⚠️ Arduino IDE won't detect this!
```

### Rule 5: Headers (.h) Can Include Libraries

**✅ CORRECT - Include library in header:**
```cpp
// MyClass.h
#ifndef MyClass_h
#define MyClass_h

#include <Wire.h>     // ✅ OK in header
#include <Arduino.h>

class MyClass {
  public:
    void begin();
};

#endif
```

```cpp
// MyProject.ino
#include "MyClass.h"  // Wire.h is included transitively

MyClass obj;

void setup() {
  obj.begin();  // ✅ Wire library is linked
}
```

**Why this works:** When Arduino preprocessor expands `#include "MyClass.h"`, it sees `#include <Wire.h>` and adds Wire library to the build.

### Rule 6: Include Chain Must Be Traceable from .ino

The chain of includes must start from a .ino file:

```
MyProject.ino → includes MyClass.h → includes Wire.h
                                   ↓
                            Wire library detected ✅
```

---

## Variable Scope & Access

### Rule 7: Global Variable Placement Strategy

**Best practice:** Declare all global variables in the **main file** (matches folder name).

**✅ RECOMMENDED:**
```cpp
// MyProject.ino (main file)
int globalCounter = 0;
String deviceName = "Arduino";
bool isConnected = false;

void setup() {
  // use variables
}
```

```cpp
// functions.ino (other file)
void incrementCounter() {
  globalCounter++;  // ✅ Can access - defined in main file (processed first)
}
```

**⚠️ PROBLEMATIC:**
```cpp
// zzz_variables.ino (processed last alphabetically)
int globalCounter = 0;

// aaa_functions.ino (processed first alphabetically)
void useCounter() {
  globalCounter++;  // ❌ ERROR - not yet declared!
}
```

### Rule 8: Cross-File Variable Access with extern

For variables defined in non-main .ino files, use `extern` declaration:

**✅ WITH EXTERN:**
```cpp
// MyProject.ino (main file)
extern int sensorValue;  // Declare it exists elsewhere

void setup() {
  Serial.println(sensorValue);  // ✅ OK
}
```

```cpp
// sensors.ino
int sensorValue = 0;  // Actual definition

void readSensor() {
  sensorValue = analogRead(A0);
}
```

---

## Function Declaration Rules

### Rule 9: Functions Work Across All .ino Files

**All functions from all .ino files are accessible everywhere** thanks to auto-generated prototypes.

```cpp
// MyProject.ino
void setup() {
  helperFromFile1();
  utilityFromFile2();
}

// file1.ino
void helperFromFile1() {
  Serial.println("From file 1");
}

// file2.ino  
void utilityFromFile2() {
  Serial.println("From file 2");
}
```

All of these work seamlessly - **order doesn't matter for functions**.

### Rule 10: Complex Signatures Need Manual Prototypes

Auto-prototype generation may fail for:

**Function pointers:**
```cpp
// Add manual prototype
void (*getHandler())(int);

void setup() {
  auto func = getHandler();
}

void (*getHandler())(int) {
  // implementation
}
```

**Default parameters with complex types:**
```cpp
// Add manual prototype
void processData(String data, int mode = 0);

void setup() {
  processData("test");
}

void processData(String data, int mode) {
  // implementation
}
```

---

## File Type Handling

### Rule 11: Different File Types, Different Rules

| File Type | Preprocessing | Concatenation | Location |
|---|---|---|---|
| `.ino` | ✅ Full Arduino preprocessing | ✅ Concatenated together | Must be in root folder |
| `.pde` | ✅ Full Arduino preprocessing | ✅ Concatenated together | Must be in root folder |
| `.cpp` | ❌ Standard C++ compilation | ❌ Compiled separately | Can be in subfolders |
| `.c` | ❌ Standard C compilation | ❌ Compiled separately | Can be in subfolders |
| `.h` | ❌ No preprocessing (just copied) | ❌ Available for `#include` | Can be in subfolders |

### Rule 12: .cpp Files Follow Standard C++ Rules

When you create `.cpp` files in your Arduino project, **standard C++ rules apply**:

**MyClass.cpp:**
```cpp
#include "MyClass.h"  // ✅ Must include header
#include <Arduino.h>  // ✅ Must include Arduino.h

// ✅ Need manual function declarations
void helperFunction();  // Forward declaration

void MyClass::myMethod() {
  helperFunction();
}

void helperFunction() {
  Serial.println("Helper");
}
```

**No automatic features in .cpp:**
- ❌ No auto-include of Arduino.h
- ❌ No auto-function prototypes  
- ❌ No concatenation with other files
- ✅ Standard C++ compilation unit

---

## Common Pitfalls

### Pitfall 1: Assuming Alphabetical Variable Access

**❌ WRONG:**
```cpp
// zzz_config.ino
const int LED_PIN = 13;

// aaa_main.ino  
void setup() {
  pinMode(LED_PIN, OUTPUT);  // ❌ ERROR - LED_PIN not yet defined
}
```

**✅ FIX - Put variables in main file:**
```cpp
// MyProject.ino (main file)
const int LED_PIN = 13;

void setup() {
  pinMode(LED_PIN, OUTPUT);  // ✅ OK
}

// aaa_functions.ino
void blinkLED() {
  digitalWrite(LED_PIN, HIGH);  // ✅ OK - main file processed first
}
```

### Pitfall 2: Including .ino Files

**❌ NEVER DO THIS:**
```cpp
// MyProject.ino
#include "functions.ino"  // ❌ WRONG! Arduino already concatenates them
```

**✅ CORRECT:**
```cpp
// MyProject.ino
// Just write your code - functions.ino is auto-concatenated

void setup() {
  helperFunction();  // ✅ Can directly call from functions.ino
}
```

### Pitfall 3: Library Include Only in .cpp

**❌ PROBLEM:**
```cpp
// MySensor.cpp
#include <Wire.h>  // Arduino IDE might not detect Wire library

void initSensor() {
  Wire.begin();
}
```

**✅ SOLUTION:**
```cpp
// MySensor.h
#include <Wire.h>  // ✅ Include in header

class MySensor {
  public:
    void init();
};

// MyProject.ino
#include "MySensor.h"  // ✅ Now Wire is detected
```

---

## Best Practices

### 1. File Organization Strategy

**Recommended structure for medium-sized projects:**
```
MyProject/
├── MyProject.ino           # Main file: includes, globals, setup(), loop()
├── 01_config.ino           # Configuration and constants
├── 02_sensors.ino          # Sensor-related functions
├── 03_display.ino          # Display functions
├── 99_utilities.ino        # Utility functions
└── src/
    ├── MyClass.h           # Complex classes in .h/.cpp
    └── MyClass.cpp
```

**Benefits:**
- Numbered prefixes control concatenation order
- Clear separation of concerns
- Main file stays clean

### 2. Main File Template

```cpp
/*
 * MyProject - Description
 * Author: Your Name
 */

// ============================================
// LIBRARY INCLUDES
// ============================================
#include <Wire.h>
#include <SPI.h>
#include "MyClass.h"

// ============================================
// GLOBAL CONSTANTS
// ============================================
const int LED_PIN = 13;
const int SENSOR_PIN = A0;

// ============================================
// GLOBAL VARIABLES
// ============================================
int sensorValue = 0;
String deviceName = "Arduino";

// ============================================
// SETUP
// ============================================
void setup() {
  Serial.begin(115200);
  pinMode(LED_PIN, OUTPUT);
  
  initSensors();     // From sensors.ino
  initDisplay();     // From display.ino
}

// ============================================
// LOOP
// ============================================
void loop() {
  readSensors();
  updateDisplay();
  delay(100);
}
```

### 3. When to Use .ino vs .cpp/.h

**Use .ino files for:**
- ✅ Simple helper functions
- ✅ Arduino-specific code
- ✅ Quick prototyping

**Use .cpp/.h files for:**
- ✅ Complex classes
- ✅ Reusable libraries
- ✅ Proper encapsulation
- ✅ Code shared across projects

### 4. Testing Strategy

**Use conditional compilation for debugging:**
```cpp
// MyProject.ino
#define DEBUG_MODE  // Comment out for production

#ifdef DEBUG_MODE
  #define DEBUG_PRINT(x) Serial.println(x)
#else
  #define DEBUG_PRINT(x)
#endif

void loop() {
  int value = readSensor();
  DEBUG_PRINT("Sensor: " + String(value));  // Only prints in debug mode
}
```

---

## Examples

### Example 1: Simple Multi-File Project

**LEDController.ino:**
```cpp
const int LED_PIN = 9;
int brightness = 0;

void setup() {
  pinMode(LED_PIN, OUTPUT);
}

void loop() {
  blinkLED();      // From blink.ino
  delay(1000);
  fadeLED();       // From fade.ino
  delay(1000);
}
```

**blink.ino:**
```cpp
void blinkLED() {
  digitalWrite(LED_PIN, HIGH);
  delay(500);
  digitalWrite(LED_PIN, LOW);
  delay(500);
}
```

**fade.ino:**
```cpp
void fadeLED() {
  for(int i = 0; i <= 255; i++) {
    analogWrite(LED_PIN, i);
    delay(10);
  }
}
```

### Example 2: Project with Classes

**SensorLogger.ino:**
```cpp
#include <SD.h>
#include "src/Logger.h"

const int SENSOR_PIN = A0;
Logger dataLogger;

void setup() {
  Serial.begin(9600);
  dataLogger.begin();
  initSensor();
}

void loop() {
  int value = readSensor();
  dataLogger.log(value);
  delay(1000);
}
```

**functions.ino:**
```cpp
void initSensor() {
  pinMode(SENSOR_PIN, INPUT);
}

int readSensor() {
  return analogRead(SENSOR_PIN);
}
```

**src/Logger.h:**
```cpp
#ifndef Logger_h
#define Logger_h

#include <Arduino.h>
#include <SD.h>

class Logger {
  private:
    File logFile;
  public:
    void begin();
    void log(int value);
};

#endif
```

**src/Logger.cpp:**
```cpp
#include "Logger.h"

void Logger::begin() {
  SD.begin(10);
  logFile = SD.open("data.txt", FILE_WRITE);
}

void Logger::log(int value) {
  if(logFile) {
    logFile.println(value);
    logFile.flush();
  }
}
```

---

## Summary Checklist

### File Structure ✓
- [ ] Main file name matches folder name
- [ ] All .ino files in root folder (no subfolders)
- [ ] .cpp/.h files can be in subfolders

### Preprocessing Understanding ✓
- [ ] Know that .ino files are concatenated
- [ ] Understand concatenation order (main first, then alphabetically)
- [ ] Know function prototypes are auto-generated

### Library Management ✓
- [ ] All library #includes in .ino files (preferably main file)
- [ ] Or #includes in .h files that are included from .ino

### Variable Management ✓
- [ ] Global variables in main file
- [ ] Use extern for cross-file variable access if needed

### Function Organization ✓
- [ ] Functions can be called from any .ino file
- [ ] Manual prototypes for complex signatures

---

**Version:** 2.0 (500-line edition)  
**Last Updated:** 2024  
**Standard:** Cursor IDE compatible

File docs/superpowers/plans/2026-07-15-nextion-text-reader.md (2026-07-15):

# Nextion Text Reader Implementation Plan

> **For agentic workers:** REQUIRED SUB-SKILL: Use superpowers:subagent-driven-development (recommended) or superpowers:executing-plans to implement this plan task-by-task. Steps use checkbox (`- [ ]`) syntax for tracking.

**Goal:** Reliably read Text component values for mould and lot validation on ESP32.

**Architecture:** Add one local raw-protocol reader to `input.ino`. It sends `get <component>.txt`, consumes Nextion string response frames, and exposes a bounded null-terminated value to existing validation handlers. Existing lookup and page update logic remains unchanged.

**Tech Stack:** Arduino ESP32, ITEADLIB Arduino Nextion, Nextion serial protocol.

## Global Constraints

- Do not modify HMI files, scanner code, login code, or ITEADLIB.
- Preserve support for alphanumeric mould and lot codes.
- Only the four failing text reads use raw protocol helper.
- Nextion text success frame is `0x70 <text bytes> 0xFF 0xFF 0xFF`.
- Helper must bound writes, null-terminate output, and fail on timeout, malformed frames, or empty values.

---

### Task 1: Add Bounded Raw Text Reader

**Files:**
- Modify: `firmware/CaesarFirmwareV1/input.ino:3-13`
- Test: Hardware or HMI simulator using `tInMF`

**Interfaces:**
- Consumes: `sendCommand(const char*)`, `nexSerial`, Arduino `millis()`.
- Produces: `bool readNextionText(const char* component, char* buffer, size_t bufferSize)`.

- [ ] **Step 1: Establish failing behavior**

Enter `1111` in front mould input and press OK. Expected current behavior: `MOULD NG`, because `tInMF.getText()` returns empty.

- [ ] **Step 2: Add raw reader below `sendInputValue()`**

```cpp
bool readNextionText(const char* component, char* buffer, size_t bufferSize) {
  if (bufferSize == 0) {
    return false;
  }

  buffer[0] = '\0';

  char command[64];
  snprintf(command, sizeof(command), "get %s.txt", component);

  while (nexSerial.available()) {
    nexSerial.read();
  }

  sendCommand(command);

  uint16_t index = 0;
  uint8_t terminatorCount = 0;
  bool receivedHeader = false;
  unsigned long start = millis();

  while (millis() - start < 200) {
    if (!nexSerial.available()) {
      continue;
    }

    uint8_t value = nexSerial.read();
    if (!receivedHeader) {
      if (value == 0x70) {
        receivedHeader = true;
      }
      continue;
    }

    if (value == 0xFF) {
      terminatorCount++;
      if (terminatorCount == 3) {
        buffer[index] = '\0';
        return index > 0;
      }
      continue;
    }

    while (terminatorCount > 0) {
      if (index < bufferSize - 1) {
        buffer[index++] = 0xFF;
      }
      terminatorCount--;
    }

    if (index < bufferSize - 1) {
      buffer[index++] = value;
    }
  }

  buffer[0] = '\0';
  return false;
}
```

- [ ] **Step 3: Compile firmware when Arduino CLI exists**

Run: `arduino-cli compile --fqbn esp32:esp32:esp32 firmware/CaesarFirmwareV1`

Expected: build succeeds. If `arduino-cli` remains unavailable, record its absence and use hardware validation.

- [ ] **Step 4: Commit reader**

```bash
git add firmware/CaesarFirmwareV1/input.ino
git commit -m "fix(nextion): read text input frames directly"
```
```

### Task 2: Route Mould And Lot Validation Through Reader

**Files:**
- Modify: `firmware/CaesarFirmwareV1/input.ino:39-126`
- Test: Hardware or HMI simulator with valid and invalid mould/lot codes.

**Interfaces:**
- Consumes: `readNextionText(const char*, char*, size_t)` from Task 1.
- Produces: Existing handlers use actual Text input values before configured lookup.

- [ ] **Step 1: Replace four library reads**

```cpp
void handleFrontMould() {
  char code[32];
  readNextionText("tInMF", code, sizeof(code));
  const Mould* mould = findMould(code);
```

```cpp
void handleBackMould() {
  char code[32];
  readNextionText("tInMB", code, sizeof(code));
  const Mould* mould = findMould(code);
```

```cpp
void handleFrontLot() {
  char code[32];
  readNextionText("tInF", code, sizeof(code));
  const Lot* lot = findLot(code);
```

```cpp
void handleBackLot() {
  char code[32];
  readNextionText("tInB", code, sizeof(code));
  const Lot* lot = findLot(code);
```

- [ ] **Step 2: Run static diff validation**

Run: `git diff --check`

Expected: no output and exit code 0.

- [ ] **Step 3: Verify valid paths on HMI**

1. On front mould page, enter or scan `1111`, press OK; confirm model, cavity, and isi populate.
2. Repeat front lot page; confirm model, target, and quota populate.
3. Repeat both on back pages.

Expected: no valid input produces `MOULD NG` or `LOT NG`.

- [ ] **Step 4: Verify invalid path on HMI**

Enter `9999` on a mould page then a lot page, press OK.

Expected: existing `MOULD NG` and `LOT NG` labels appear; no system values persist from unknown code.

- [ ] **Step 5: Commit integration**

```bash
git add firmware/CaesarFirmwareV1/input.ino
git commit -m "fix(input): validate mould and lot text values"
```
```

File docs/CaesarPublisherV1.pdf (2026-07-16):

# CaesarPublisherV1

Hardware simulator untuk CaesarFirmwareV1. ESP32 ini mensimulasikan siklus mesin cetak tanpa mesin asli. Operator tekan tombol di sensor, firmware kirim sinyal START dan siklus selesai ke broker MQTT yang sama dengan simulator software.

# Perbedaan dengan Firmware Utama

Aspek | CaesarFirmwareV1 | CaesarPublisherV1
Fungsi | Kontrol mesin cetak asli | Simulasi siklus via sensor
HMI Nextion | Ya | Tidak
Barcode scanner | Ya | Tidak
Quota/ISI tracking | Ya | Tidak
Operator/Mould/Lot | Ya | Tidak
Interlock GPIO25 | Ya | Tidak
MQTT finish topic | Sama | Sama
MQTT broker | Sama | Sama

PublisherV1 mengirim data ke topik yang sama dengan simulator software ( start/... dan finish/... ). CaesarFirmwareV1 tidak tahu bedanya. Data dari hardware atau software sama saja.

# Cara Kerja

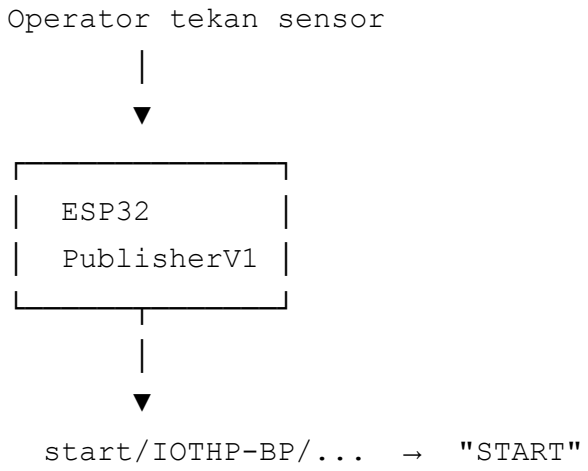
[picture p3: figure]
Operator tekan sensor │ ▼ ┌──────────────┐; │ ESP32; │ PublisherV1 │ └──────┬───────┘ │ ▼ start/IOTHP-BP/... → "START"

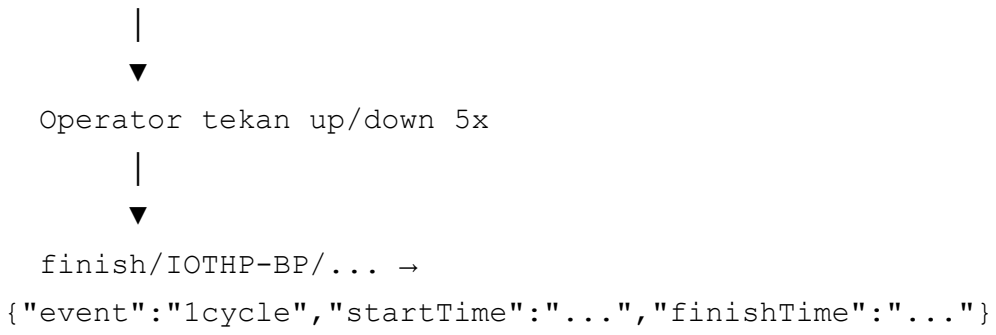
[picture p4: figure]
│ ▼ Operator tekan up/down 5x │ ▼ finish/IOTHP-BP/... → {"event":"1cycle","startTime":"...","finishTime":"..."}

# Sensor

Sensor | Pin | Fungsi
Front (depan) | GPIO32 | Mulai siklus layer depan
Back (belakang) | GPIO35 | Mulai siklus layer belakang
Up (naik) | GPIO33 | Gerakan naik (step 1, 3, 5)
Down (turun) | GPIO25 | Gerakan turun (step 2, 4)
WiFi LED | GPIO26 | Indikator koneksi WiFi

# File

## config.h

Pengaturan utama. Semua bisa diubah tanpa menyentuh kode program.

Define | Value | Fungsi
WIFI_SSID | TIMEO | SSID WiFi
WIFI_PASS | 1234Saja | Password WiFi
MQTT_SERVER | broker.hivemq.com | Broker MQTT
MQTT_PORT | 1883 | Port broker
MQTT_ADDR | 91c21b8614cd | ID device
MQTT_CLIENT_ID | CaesarPublisher/91c21b8614cd | Client ID MQTT
START_TOPIC | start/IOTHP-BP/91c21b8614cd | Topik sinyal START
FINISH_TOPIC | finish/IOTHP-BP/91c21b8614cd | Topik siklus selesai
CONTROL_TOPIC | CONTROL/IOTHP-BP/91c21b8614cd | Topik perintah

Define | Value | Fungsi
NTP_SERVER | pool.ntp.org | Server waktu
WIB_TIMEZONE | WIB-7 | Zona waktu
FRONT_PIN | GPIO32 | Sensor depan
BACK_PIN | GPIO35 | Sensor belakang
UP_PIN | GPIO33 | Sensor naik
DOWN_PIN | GPIO25 | Sensor turun
WIFI_LED_PIN | GPIO26 | LED WiFi
OTA_USERNAME | admin | Username update firmware
OTA_PASSWORD | 123654789 | Password update firmware

## CaesarPublisherV1.ino

File utama yang menghubungkan semua bagian. Berisi objek global dan alur utama program.

Objek global:

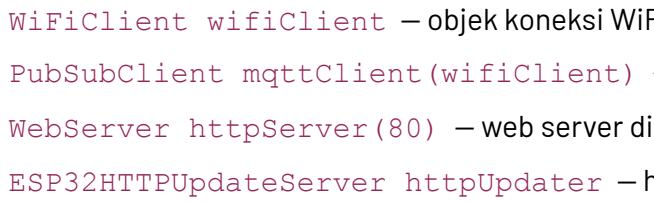
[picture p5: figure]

WiFiClient wifiClient — objek koneksi WiFi
PubSubClient mqttClient(wifiClient) — objek koneksi MQTT
WebServer httpServer(80) — web server di port 80 untuk OTA update ESP32HTTPUpdateServer httpUpdater — handler halaman web update firmware

setup() — dijalankan sekali saat ESP32 dinyalakan:

1. Serial.begin(115200) — nyalakan serial monitor untuk debug
2. pinMode(FRONT_PIN, INPUT) — set GPIO32 sebagai input (sensor depan)
3. pinMode(BACK_PIN, INPUT) — set GPIO35 sebagai input (sensor belakang)
4. pinMode(UP_PIN, INPUT) — set GPIO33 sebagai input (sensor naik)
5. pinMode(DOWN_PIN, INPUT) — set GPIO25 sebagai input (sensor turun)
6. pinMode(WIFI_LED_PIN, OUTPUT) — set GPIO26 sebagai output (LED WiFi)
7. digitalWrite(WIFI_LED_PIN, LOW) — matikan LED saat awal
8. initCycleInputs() — baca posisi awal semua sensor agar tidak false trigger
9. initTime() — set zona waktu WIB sebelum NTP jalan
10. setupWifi() — mulai koneksi WiFi
11. setupMqtt() — set alamat broker dan callback
12. httpUpdater.setup(...) — daftarkan halaman web update firmware di /update

13. httpServer.begin() — nyalakan web server di port 80

loop() — dijalankan ratusan kali per detik:

1. mqttLoop() — proses WiFi reconnect, MQTT reconnect, dan pesan masuk
2. syncTime() — ambil waktu dari internet jika belum sinkron
3. httpServer.handleClient() — handle request dari browser (untuk OTA update)
4. updateCycleInputs() — baca semua sensor, proses logika siklus

## wifi_mqtt.ino

Mengatur koneksi WiFi dan MQTT. Semua komunikasi dengan server melewati file ini.

Variabel global:

lastWifiAttempt — timestamp kapan terakhir coba sambung WiFi. Digunakan untuk delay 5 detik agar ESP32 tidak spam reconnect.
lastMqttAttempt — timestamp kapan terakhir coba sambung MQTT. Delay sama, 5 detik.

mqttCallback(topic, payload, length) — handler saat terima pesan dari server. Dipanggil otomatis oleh PubSubClient saat ada pesan masuk. Cek dua kondisi:

1. Pesan datang dari CONTROL_TOPIC DAN isinya REBOOT (6 karakter) → restart ESP32 via

ESP.restart()
2. Selain itu → diabaikan

PublisherV1 hanya menerima satu jenis pesan: perintah reboot.

setupWifi() — mulai koneksi WiFi:

1. WiFi.mode(WIFI_STA) — set mode station (bukan access point)
2. WiFi.setHostname(MQTT_CLIENT_ID) — set nama device di jaringan
3. WiFi.begin(WIFI_SSID, WIFI_PASS) — mulai koneksi
4. lastWifiAttempt = millis() — catat waktu percobaan

setupMqtt() — konfigurasi MQTT:

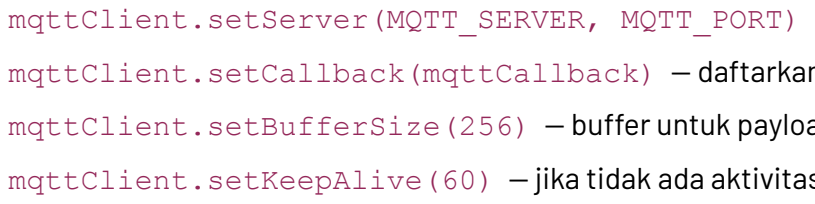
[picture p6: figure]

1. mqttClient.setServer(MQTT_SERVER, MQTT_PORT) — set alamat broker
2. mqttClient.setCallback(mqttCallback) — daftarkan handler pesan masuk
3. mqttClient.setBufferSize(256) — buffer untuk payload (cukup untuk JSON siklus)
4. mqttClient.setKeepAlive(60) — jika tidak ada aktivitas 60 detik, koneksi putus reconnectWifi() — auto-reconnect WiFi:
1. Jika WiFi sudah terhubung → skip
2. Jika belum dan sudah lewat 5 detik sejak percobaan terakhir → putuskan WiFi, sambung ulang
3. Delay 5 detik mencegah ESP32 mencoba sambung ulang terlalu sering

reconnectMqtt() — auto-reconnect MQTT:

1. Jika MQTT sudah terhubung → skip
2. Jika belum dan sudah lewat 5 detik → coba mqttClient.connect()
3. Setelah terhubung → subscribe CONTROL_TOPIC agar bisa terima perintah REBOOT

mqttLoop() — fungsi utama yang dipanggil dari loop() :

1. reconnectWifi() — coba sambung WiFi jika perlu
2. digitalWrite(WIFI_LED_PIN, ...) — nyalakan LED jika WiFi terhubung, matikan jika tidak
3. Jika WiFi belum terhubung → skip (tidak bisa proses MQTT tanpa WiFi)
4. reconnectMqtt() — coba sambung MQTT jika perlu
5. Jika MQTT terhubung → mqttLoop() untuk proses pesan masuk

## time.ino

Pengambilan waktu dari internet (NTP). Waktu digunakan untuk timestamp di payload siklus.

Variabel global:

ntpConfigured — apakah sudah pernah jalankan configTzTime() . Cukup sekali. ntpReady — apakah waktu dari NTP sudah berhasil diambil
lastNtpAttempt — kapan terakhir coba ambil waktu
NTP_RETRY_INTERVAL — interval retry 1 detik

initTime() — panggilan sekali saat setup() :

1. setenv("TZ", WIB_TIMEZONE, 1) — set variabel environment zona waktu ke "WIB-7"
2. tzset() — beritahu sistem bahwa semua waktu harus dikonversi ke WIB

Tidak perlu internet untuk fungsi ini. Waktu belum tersedia — hanya zona waktu yang diatur.

syncTime() — sinkronisasi waktu dari NTP. Dipanggil terus-menerus dari loop() :

1. Jika waktu sudah ready → skip (sudah sinkron)
2. Jika WiFi belum terhubung → skip (butuh internet)

3. Jika belum lewat 1 detik sejak percobaan terakhir → skip (delay)
4. Jalankan configTzTime(WIB_TIMEZONE, NTP_SERVER) sekali pertama
5. Coba ambil waktu dari server via getLocalTime()
6. Jika berhasil → ntpReady = true

Setelah ntpReady = true , waktu tersedia untuk semua fungsi yang membutuhkan timestamp.

getTimestamp(buffer, length) — ambil waktu saat ini dan format ke ISO8601 WIB:

1. Jika NTP belum ready → return false
2. Ambil waktu dari sistem via getLocalTime()
3. Format ke string: YYYY-MM-DDTHH:MM:SS.000+07:00
4. Return true jika berhasil

Contoh output: 2026-07-17T14:30:00.000+07:00

Waktu tidak tersedia sampai WiFi terhubung dan NTP sinkron (biasanya 2-5 detik setelah WiFi nyambung).

## cycle.ino

Logika siklus dari sensor. File ini menentukan kapan siklus dimulai, bagaimana menghitung gerakan, dan kapan siklus selesai.

Variabel state:

frontLatched / backLatched / upLatched / downLatched — posisi terakhir tiap sensor. Digunakan untuk mendeteksi tepi naik (sensor baru saja ditekan, bukan sedang ditekan terus).
cycleStarted — apakah siklus sedang berjalan
expectUp — gerakan selanjutnya harus up (mencegah double count)
stepCount — jumlah gerakan valid yang terhitung
cycleStartTime — waktu saat siklus dimulai (dari NTP)

initCycleInputs() — panggilan sekali saat setup() :
Baca posisi awal semua sensor. Tanpa ini, jika sensor sudah ditekan saat ESP32 nyala, firmware akan false trigger siklus baru di detik pertama.

publishStart() — kirim sinyal START ke broker:

1. Cek MQTT connected. Jika tidak → skip.
2. Publish "START" tanpa retained ke START_TOPIC

3. Pesan ini memberitahu CaesarFirmwareV1 bahwa siklus baru dimulai

publishCycle() — kirim JSON siklus selesai:

1. Cek MQTT connected. Jika tidak → skip.

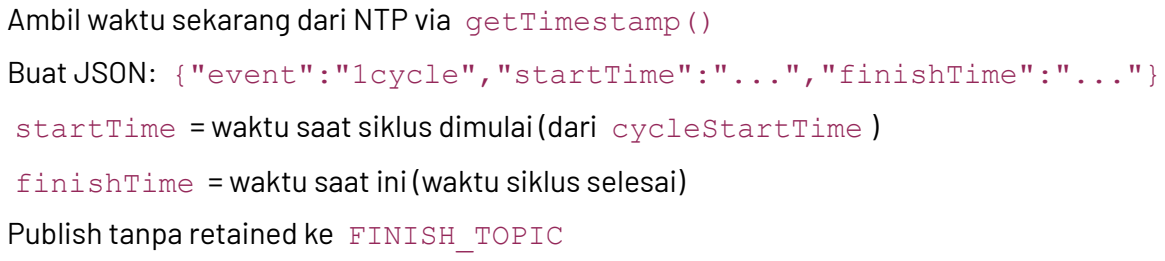
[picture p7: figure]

2. Ambil waktu sekarang dari NTP via getTimestamp()
3. Buat JSON: {"event":"1cycle","startTime":"...","finishTime":"..."}
4. startTime = waktu saat siklus dimulai (dari cycleStartTime )
5. finishTime = waktu saat ini (waktu siklus selesai)
6. Publish tanpa retained ke FINISH_TOPIC

CaesarFirmwareV1 terima JSON ini → increment siklus, kurangi kuota, update layar, kirim data ke server.

startCycle() — mulai siklus baru:

1. Jika siklus sudah berjalan ( cycleStarted == true ) → skip (tidak mulai siklus baru sebelum yang sebelumnya selesai)
2. Ambil waktu dari NTP. Jika gagal → skip (timestamp tidak tersedia)
3. Set cycleStarted = true
4. Reset stepCount = 0
5. Set expectUp = true (gerakan pertama harus up)
6. Simpan waktu mulai ke cycleStartTime
7. publishStart() — kirim sinyal START

finishCycle() — selesaikan siklus:

1. publishCycle() — kirim JSON siklus selesai
2. Set cycleStarted = false
3. Reset stepCount = 0
4. Set expectUp = true

updateCycleInputs() — fungsi utama yang dipanggil dari loop() . Membaca semua sensor dan memproses logika siklus:

1. Baca posisi semua sensor: digitalRead(FRONT_PIN) == LOW artinya sensor ditekan
2. Deteksi tepi naik: sensor baru saja ditekan (belum ditekan sebelumnya)
frontPressed && !frontLatched → sensor depan baru ditekan backPressed && !backLatched → sensor belakang baru ditekan
3. Jika Front/Back baru ditekan → startCycle()
4. Deteksi gerakan up: sensor up ditekan, sebelumnya tidak, expectUp == true , dan siklus berjalan stepCount++ , expectUp = false
5. Deteksi gerakan down: sensor down ditekan, sebelumnya tidak, expectUp == false , dan siklus berjalan
stepCount++ , expectUp = true
6. Update posisi terakhir semua sensor (untuk deteksi tepi di loop berikutnya)
7. Jika stepCount >= 5 dan siklus berjalan → finishCycle()

Pola gerakan:

Sensor Front/Back ditekan → START
Up (step 1) → expectUp = false Down (step 2) → expectUp = true Up (step 3) → expectUp = false Down (step 4) → expectUp = true
Up (step 5) → FINISH

Total 5 gerakan: 3 up + 2 down (atau 2 up + 3 down, tergantung urutan awal).

# Topik MQTT

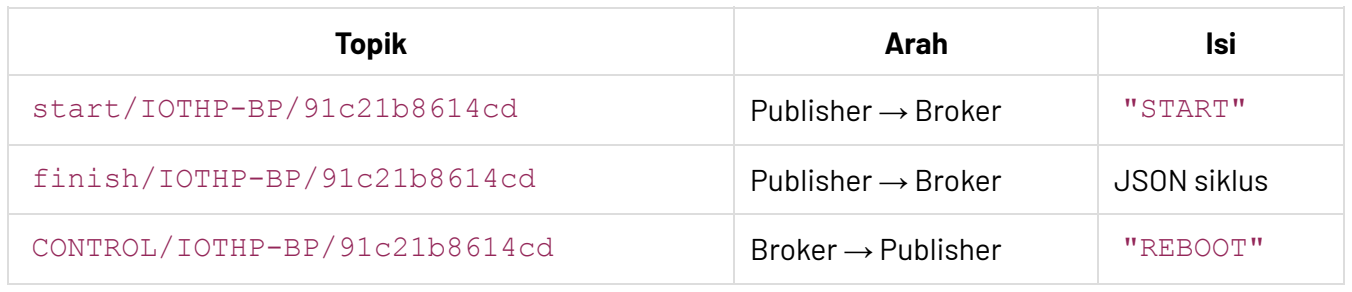
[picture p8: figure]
Topik; Arah; Isi; start/IOTHP-BP/91c21b8614cd; Publisher → Broker; "START"; finish/IOTHP-BP/91c21b8614cd; JSON siklus; CONTROL/IOTHP-BP/91c21b8614cd; Broker → Publisher; "REBOOT"

# OTA Update

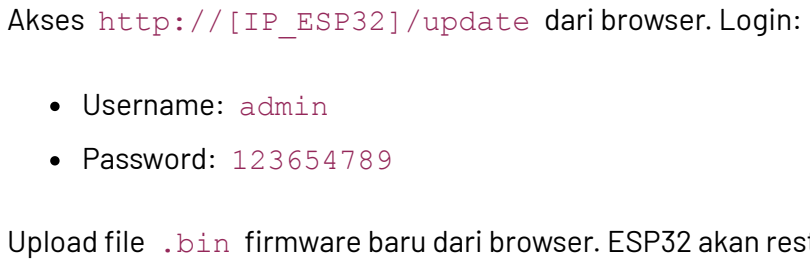
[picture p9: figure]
Akses http://[IP_ESP32]/update dari browser. Login:; Username: admin; Password: 123654789

Upload file .bin firmware baru dari browser. ESP32 akan restart otomatis setelah upload selesai.

# Troubleshooting

Masalah | Solusi

Masalah | Solusi
LED WiFi mati | WiFi tidak terhubung. Cek SSID dan password di config.h
Siklus tidak mulai | Pastikan sensor Front/Back ditekan dulu
Siklus tidak selesai | Hitung 5 gerakan: up, down, up, down, up
Data tidak sampai ke firmware | Cek koneksi internet, pastikan broker.hivemq.com:1883 bisa diakses
Waktu salah di payload | NTP belum sinkron. Tunggu beberapa detik setelah WiFi terhubung

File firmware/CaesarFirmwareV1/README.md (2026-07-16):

# CaesarFirmwareV1

Firmware ESP32 yang mengontrol mesin cetak Caesar. Semua operasi — login operator, input mould, input lot, pencacahan siklus, pencatatan waktu henti, pencatatan produk cacat, hingga pengiriman data ke server — berjalan dari firmware ini.

## Cara Kerja

```
┌──────────────┐      ┌──────────────┐
│   OPERATOR   │─────▶│  MESIN CETAK │
│  (di layar)  │      │  (bergerak)  │
└──────┬───────┘      └──────┬───────┘
       │                     │
       ▼                     ▼
┌──────────────┐      ┌──────────────┐
│  HMI Nextion │◀────▶│  ESP32       │
│  (layar sentuh)│     │  (otak system)│
└──────────────┘      └──────┬───────┘
                             │
                             ▼
                      ┌──────────────┐
                      │  MQTT Broker │
                      │  (server)    │
                      └──────────────┘
```

Simulator kirim sinyal START. Firmware hitung 5 gerakan naik-turun. Simulator kirim sinyal siklus selesai. Firmware tambah jumlah siklus, kurangi kuota, update layar, kirim data ke server.

## Fitur

| Bagian | Fungsi |
|---|---|
| Login | Operator login sebelum jalankan mesin |
| Mould | Input cetakan (model, jumlah lubang) |
| Lot | Input nomor lot dan target produksi |
| Siklus | Hitung berapa kali mesin mencetak |
| Downtime | Catat waktu mesin berhenti dan alasannya |
| NG | Catat produk cacat |
| Interlock | Pengaman: mesin tidak siap, siklus tidak jalan |
| Waktu | Jam WIB dari internet (NTP) |
| Simulasi | Mode otomatis untuk testing |

---

## File

### config.h

Pengaturan utama. Semua bisa diubah tanpa menyentuh kode program.

**WiFi:**
- SSID: `TIMEO`
- Password: `1234Saja`

**MQTT:**
- Broker: `broker.hivemq.com`
- Port: `1883`
- Device ID: `91c21b8614cd`

**Topik MQTT:**

| Topik | Fungsi |
|---|---|
| `finish/IOTHP-BP/91c21b8614cd` | Menerima sinyal siklus selesai dari simulator |
| `dataA/IOTHP-BP/91c21b8614cd` | Mengirim data layer depan (retained) |
| `dataB/IOTHP-BP/91c21b8614cd` | Mengirim data layer belakang (retained) |
| `event/IOTHP-BP/91c21b8614cd` | Mengirim event downtime dan NG |
| `CONTROL/IOTHP-BP/91c21b8614cd` | Menerima perintah REBOOT |

**Waktu:**
- Server NTP: `pool.ntp.org`
- Zona waktu: WIB (UTC+7)

**Tabel Data:**

| Tabel | Isi |
|---|-----|
| Operator | ID 1111-3333, nama lengkap |
| Mould | Kode 1111-3333, nama model, jumlah cavity |
| Lot | Kode 1111-3333, nama model, target produksi |

Edit tabel di `config.h` sesuai data produksi aktual.

---

### CaesarFirmwareV1.ino

File utama yang menghubungkan semua bagian. Berisi deklarasi komponen HMI, variabel global, dan alur utama program.

**Variabel global:**
- `WiFiClient wifiClient` — objek koneksi WiFi
- `PubSubClient mqttClient` — objek koneksi MQTT, pakai `wifiClient` sebagai transport
- `char cycleStartTime[32]` / `char cycleFinishTime[32]` — menyimpan waktu mulai dan selesai siklus terakhir dari simulator
- `LayerComponents` — struct berisi nama-nama komponen di HMI untuk tiap layer (cycle, output, ok, ng, quota, isi, target, model, lot, operatorName, operatorId)
- `LayerState` — struct berisi nilai produksi aktual untuk satu layer
- `uint8_t currentPageId` — nomor halaman HMI yang sedang aktif. Scanner membaca nilai ini untuk tahu harus kirim input ke mana.

**Deklarasi komponen HMI:**
Semua halaman (`NexPage`), tombol (`NexButton`), teks (`NexText`), angka (`NexNumber`), dan variabel (`NexVariable`) dideklarasikan di sini. Setiap komponen punya nomor halaman, nomor komponen, dan nama. Contoh: `NexButton bOkF = NexButton(1, 2, "bOkF")` artinya tombol "bOkF" di halaman 1, komponen nomor 2.

`nex_listen_list` — array semua komponen yang harus didengarkan. `nexLoop(nex_listen_list)` di `loop()` akan memeriksa apakah ada tombol yang ditekan operator.

**`setup()`** — dijalankan sekali saat ESP32 dinyalakan:
1. `Serial.begin(115200)` — nyalakan serial monitor untuk debug
2. `SCANNER_SERIAL.begin(...)` — nyalakan Serial2 untuk barcode scanner (RX=GPIO16, TX=GPIO17, 9600 baud)
3. `initTimeSource()` — set zona waktu WIB atau inisialisasi modul RTC
4. `initInterlock()` — set GPIO25 sebagai OUTPUT, matikan dulu (LOW)
5. `registerLoginCallbacks()` — daftarkan semua callback tombol login, logout, dan navigasi halaman
6. `registerInputCallbacks()` — daftarkan callback tombol mould, lot, dan NG submit
7. `registerDowntimeCallbacks()` — daftarkan callback tombol downtime (mulai dan clear)
8. `registerSimulationCallbacks()` — daftarkan callback tombol auto-cycle
9. `setupWifi()` — mulai koneksi WiFi
10. `setupMqtt()` — set broker dan callback MQTT

**`loop()`** — dijalankan ratusan kali per detik:
1. `nexLoop(nex_listen_list)` — baca semua tombol di HMI. Jika ada yang ditekan, panggil callback yang terdaftar.
2. `mqttLoop()` — proses koneksi WiFi, MQTT, dan pesan masuk
3. `syncTimeSource()` — ambil waktu dari NTP jika belum sinkron
4. `handleScanner()` — baca input dari barcode scanner
5. `updateTnow()` — kirim timestamp lengkap ke `pageSys.tNow.txt` tiap 1 detik
6. `updateSimulation()` — jalankan auto-cycle jika mode simulasi aktif

---

### wifi_mqtt.ino

Mengatur koneksi WiFi dan MQTT. Semua komunikasi dengan server melewati file ini.

**Variabel global:**
- `lastWifiAttempt` — timestamp kapan terakhir coba sambung WiFi. Digunakan untuk delay 5 detik agar ESP32 tidak spam reconnect.
- `lastMqttAttempt` — timestamp kapan terakhir coba sambung MQTT. Delay sama, 5 detik.

**`publishEvent(json)`** — kirim event ke server (downtime/NG). Cek MQTT connected dulu. Publish non-retained ke `EVENT_TOPIC`. Non-retained artinya pesan tidak disimpan server — jika subscriber offline saat pesan dikirim, subscriber tidak akan terima pesan ini nanti.

**`mqttCallback(topic, payload, length)`** — handler saat terima pesan dari server. Dua jenis pesan yang dihandle:
1. Dari `CONTROL_TOPIC`, isi `REBOOT` (6 karakter) → restart ESP32 via `ESP.restart()`
2. Dari `FINISH_TOPIC`, isi JSON `1cycle` → parse JSON, ambil `startTime` dan `finishTime`, panggil `handleMqttCycle()`

Jika pesan bukan dari kedua topik ini → diabaikan.

**`setupWifi()`** — set WiFi mode sebagai station (bukan access point), set hostname ke `MQTT_CLIENT_ID` agar mudah dikenali di jaringan, mulai koneksi ke SSID dan password yang ditentukan.

**`setupMqtt()`** — set alamat broker dan port, daftarkan `mqttCallback` untuk pesan masuk, set buffer 256 byte (cukup untuk payload JSON siklus), set keep alive 60 detik (jika tidak ada aktivitas MQTT selama 60 detik, koneksi putus otomatis), set socket timeout 5 detik.

**`reconnectWifi()`** — jika WiFi sudah terhubung → skip. Jika belum dan sudah lewat 5 detik sejak percobaan terakhir → putuskan WiFi lalu sambung ulang. Delay 5 detik mencegah ESP32 mencoba sambung ulang terlalu sering.

**`reconnectMqtt()`** — logika sama. Jika MQTT sudah terhubung → skip. Jika belum dan sudah lewat 5 detik → coba `mqttClient.connect()`. Setelah terhubung → subscribe `CONTROL_TOPIC` (untuk REBOOT) dan `FINISH_TOPIC` (untuk siklus dari simulator).

**`mqttLoop()`** — fungsi utama yang dipanggil dari `loop()`. Urutan:
1. `reconnectWifi()` — coba sambung WiFi jika perlu
2. Set LED WiFi: HIGH jika terhubung, LOW jika putus
3. Jika WiFi belum terhubung → skip (tidak bisa proses MQTT tanpa WiFi)
4. `reconnectMqtt()` — coba sambung MQTT jika perlu
5. Jika MQTT terhubung → `mqttLoop()` untuk proses pesan masuk

---

### cycle.ino

Penghitung siklus dari simulator. Dipanggil saat firmware terima JSON `1cycle` dari `FINISH_TOPIC`.

**Variabel state:**
- `frontCycle` / `backCycle` — jumlah siklus untuk layer depan dan belakang
- `frontOutput` / `backOutput` — jumlah output untuk tiap layer
- `frontQuota` / `backQuota` — sisa kuota produksi
- `frontIsi` / `backIsi` — isi per cetakan (dari mould)
- `frontNg` / `backNg` — jumlah produk cacat

**`handleMqttCycle(startTime, finishTime)`** — fungsi utama. Alur:
1. Baca `pageSys.nMReady` dari HMI. Jika `0` → interlock merah, siklus tidak jalan. Return.
2. Baca 11 nilai dari HMI: siklus, output, kuota, isi, NG untuk depan dan belakang. Jika gagal baca → return.
3. Cek kondisi: jika `frontIsi==0` atau `backIsi==0` → mould belum diisi. Jika `frontQuota < frontIsi` atau `backQuota < backIsi` → kuota habis. Dalam kedua kasus → update status saja, tidak increment siklus.
4. Simpan `startTime` dan `finishTime` ke variabel global.
5. Increment siklus: `frontCycle++`, `backCycle++`
6. Tambah output: `frontOutput += frontIsi`, `backOutput += backIsi`
7. Kurangi kuota: `frontQuota -= frontIsi`, `backQuota -= backIsi`
8. Hitung OK: `frontOk = frontOutput - frontNg`, `backOk = backOutput - backNg`
9. Update semua komponen HMI: siklus, output, kuota, OK untuk depan dan belakang
10. Update tampilan simulation dan dashboard
11. Update dashboard NG display
12. `updateDashboardStatus()` — hitung ulang status mesin (mungkin berubah karena kuota berkurang)
13. `publishBothLayers()` — kirim data lengkap ke server (retained)

Siklus selalu increment kedua layer sekaligus. Firmware tidak membedakan layer depan atau belakang dalam siklus.

---

### dashboard.ino

Logika status mesin. Menentukan apakah mesin siap atau terkunci berdasarkan kondisi saat ini.

**`getFrontDashboardStatus(login, machineDowntime, downtime, quota, cavity, isi)`** — cek kondisi secara berurutan (prioritas dari atas):
1. `login == 0` → "BP DEPAN LOCKED" (operator belum login)
2. `machineDowntime != 0` → "BP DEPAN MC DOWNTIME" (mesin sedang downtime)
3. `downtime != 0` → "BP DEPAN DOWNTIME" (layer ini sedang downtime)
4. `quota < isi` → "BP DEPAN NO LOT" (kuota kurang dari isi per cetakan)
5. `cavity == 0` → "BP DEPAN NO MOULD" (belum pilih mould)
6. `isi == 0` → "BP DEPAN ISI 0" (isi per cetakan kosong)
7. Sisanya → "BP DEPAN READY"

**`getBackDashboardStatus()`** — logika sama untuk layer belakang.

**`updateDashboardStatus()`** — fungsi utama yang dipanggil dari banyak tempat:
1. Baca 11 nilai dari HMI: login depan/belakang, downtime mesin, downtime depan/belakang, kuota depan/belakang, cavity depan/belakang, isi depan/belakang
2. Jika gagal baca → set interlock LOW (fail-safe), return
3. Hitung status untuk depan dan belakang
4. Cek apakah keduanya READY → `machineReady`
5. Kirim status teks ke dashboard: `tFStat`, `tBStat`
6. Set `nFReady`, `nBReady`, `nMReady` di HMI
7. Set warna `tILock`: hijau (2024) jika siap, merah (63488) jika tidak
8. Kosongkan teks `tILock`
9. `setInterlock(machineReady)` — drive GPIO25 sesuai kondisi

**`syncSimulationTargets()`** — baca target dari `pageSys.nFTarget`/`nBTarget`, kirim ke `pageSim.nSTgtF`/`nSTgtB`. Dipanggil saat operator buka halaman simulasi.

---

### downtime.ino

Pencatatan waktu henti mesin. Mengelola mulai dan clear downtime untuk layer depan, belakang, dan mesin.

**`sendDowntimeText(format, value)`** — helper untuk kirim perintah format ke HMI. Contoh: `sendDowntimeText("pageSys.tFDtType.txt=\"%s\"", reason)` → kirim `pageSys.tFDtType.txt="BAHAN TELAT"`.

**`showDowntimeInfo(pageName)`** — navigasi ke halaman info downtime:
1. `sendCommand("page pageDashboard")` — buka dashboard dulu
2. `delay(200)` — tunggu 200ms agar dashboard selesai render
3. `lockInterlock()` — kunci interlock
4. `delay(100)` — tunggu 100ms agar perintah interlock sampai
5. `sendDowntimeText("page %s", pageName)` — buka halaman info downtime

Dashboard harus muncul dulu karena komponen `tILock` ada di halaman dashboard. Jika langsung kirim perintah interlock saat masih di halaman downtime, perintah tidak sampai.

**`lockInterlock()`** — kunci mesin:
1. `setInterlock(false)` — GPIO25 LOW
2. `sendCommand("pageSys.nMReady.val=0")` — set mesin tidak siap
3. `sendCommand("tILock.bco=63488")` — warna interlock merah
4. `sendCommand("tILock.txt=\"\"")` — kosongkan teks interlock

**`startFrontDowntime(reason)`** — mulai downtime layer depan:
1. Set `pageSys.nFDtAct.val=1` (flag downtime aktif)
2. Tulis tipe downtime ke `pageSys.tFDtType`
3. Copy waktu dari `pageSys.tNow.txt` ke `pageSys.tFDtStart.txt`
4. `lockInterlock()` — kunci mesin
5. Ambil timestamp dari NTP, buat JSON event, publish ke server
6. `updateDashboardStatus()` — update status (sekarang DOWNTIME)
7. `showDowntimeInfo("pageDtInfoF")` — buka halaman info downtime depan

**`startBackDowntime()`** / **`startMachineDowntime()`** — logika sama untuk layer belakang dan mesin.

**`clearFrontDowntime()`** — clear downtime depan:
1. Reset flag: `nFDtAct=0`, kosongkan tipe dan waktu
2. Set `pageSys.nDtPop.val=0`
3. Ambil timestamp, publish event `downtime_clear`
4. `updateDashboardStatus()` — status mungkin berubah ke READY
5. `sendCommand("page pageDashboard")` — kembali ke dashboard

**`clearBackDowntime()`** / **`clearMachineDowntime()`** — logika sama.

**Callback tombol:**
- `bBhnFCallback` → `startFrontDowntime("BAHAN TELAT")`
- `bTggPnsFCallback` → `startFrontDowntime("TUNGGU PANAS")`
- `bMoffFCallback` → `startFrontDowntime("MOULD OFF")`
- `bLbhPnsFCallback` → `startFrontDowntime("LEBIH PANAS")`
- `bKrgPnsFCallback` → `startFrontDowntime("KURANG PANAS")`
- `bTrialFCallback` → `startFrontDowntime("TRIAL")`
- `bRunFCallback` → `clearFrontDowntime()`
- `bBackDtFCallback` → kembali ke dashboard
- Back dan Machine punya callback setara

**`registerDowntimeCallbacks()`** — daftarkan semua callback ke tombol yang sesuai.

---

### input.ino

Penerimaan input dari layar HMI dan barcode scanner. File terbesar (469 baris). Berisi semua handler untuk mould, lot, NG, dan helper functions untuk komunikasi dengan HMI.

**Komunikasi dasar dengan HMI (Nextion):**

**`sendInputText(component, value)`** — kirim teks ke komponen HMI. Format: `{component}.txt="{value}"`. Contoh: `sendInputText("pageSys.tFMld", "1111")` → kirim `pageSys.tFMld.txt="1111"`.

**`sendInputValue(component, value)`** — kirim angka ke komponen HMI. Format: `{component}.val={value}`. Contoh: `sendInputValue("pageSys.nFCav", 8)` → kirim `pageSys.nFCav.val=8`.

**`readNextionText(component, buffer, bufferSize)`** — baca teks dari HMI. Kirim perintah `get {component}.txt`. Tunggu jawaban dari HMI (timeout 200ms). Header jawaban: 0x70. Data: karakter biasa. Terminator: 3x 0xFF berturut-turut. Return true jika berhasil.

**`readNextionValue(component, value)`** — baca angka dari HMI. Kirim perintah `get {component}.val`. Header jawaban: 0x71. Data: 4 byte little-endian (nilai angka). Terminator: 3x 0xFF. Return true jika berhasil.

**Proses mould:**

**`fillFrontMouldInput(code)`** — isi kolom input mould depan dengan kode barcode.

**`handleFrontMould()`** — proses input mould depan:
1. Baca kode dari `tInMF` (kolom input)
2. Cari di tabel `MOULDS` di config.h
3. Jika tidak ditemukan → tampilkan "MOULD NG", set cavity=0, isi=0
4. Jika ditemukan → tampilkan nama model, set cavity dan isi (jumlah lubang), update semua komponen HMI terkait (pageSys, pageLot, pageDashboard, pageSim), update dashboard status, kirim data ke server

**`clearFrontMould()`** — kosongkan semua field mould depan, reset cavity dan isi ke 0.

**`handleBackMould()`** / **`clearBackMould()`** — logika sama untuk layer belakang.

**Proses lot:**

**`fillFrontLotInput(code)`** — isi kolom input lot depan dengan kode barcode. Juga baca cavity dari HMI dan tampilkan di `nIsiLotF`.

**`handleFrontLot()`** — proses input lot depan:
1. Baca kode dari `tInF`
2. Cari di tabel `LOTS` di config.h
3. Jika tidak ditemukan → tampilkan "LOT NG"
4. Baca cavity dan isi dari HMI. Validasi: cavity harus >0, isi harus >0, isi ≤ cavity
5. Jika semua valid → set target dan kuota, update semua komponen HMI, update dashboard, kirim data ke server

**`clearFrontLot()`** — kosongkan semua field lot depan, reset target dan kuota ke 0.

**`handleBackLot()`** / **`clearBackLot()`** — logika sama untuk layer belakang.

**Proses NG:**

**`publishNgEvent(layer, typeComponent, countComponent, acceptedComponent)`** — kirim event produk cacat:
1. Baca `acceptedComponent` (flag dari HMI bahwa operator sudah submit). Jika 0 → return.
2. Baca `countComponent` (jumlah NG). Jika 0 → return.
3. Baca `typeComponent` (tipe NG, misal "SCRATCH"). Jika kosong → return.
4. Ambil timestamp dari NTP
5. Buat JSON: `{"event":"ng_submit","layer":"...","ng_type":"...","ng_count":...,"timestamp":"..."}`
6. Publish ke server
7. Clear jumlah NG dan flag submit di HMI

**`bOkNgFCallback()`** → `publishNgEvent("FRONT", "pageSys.tFNgType", "nNgInF", "pageSys.nFNgEvent")`
**`bOkNgBCallback()`** → `publishNgEvent("BACK", "pageSys.tBNgType", "nNgInB", "pageSys.nBNgEvent")`

**`registerInputCallbacks()`** — daftarkan semua callback tombol mould, lot, dan NG.

---

### interlock.ino

Pengaman mesin via GPIO25. File kecil (10 baris) dengan dua fungsi.

**`initInterlock()`** — panggilan sekali saat `setup()`:
1. `pinMode(INTERLOCK_PIN, OUTPUT)` — set GPIO25 sebagai output
2. `digitalWrite(INTERLOCK_PIN, LOW)` — matikan dulu (mesin terkunci saat baru nyala)

**`setInterlock(ready)`** — set kondisi interlock:
- `ready = true` → `digitalWrite(INTERLOCK_PIN, HIGH)` → mesin siap
- `ready = false` → `digitalWrite(INTERLOCK_PIN, LOW)` → mesin terkunci

Dipanggil dari dua tempat:
1. `updateDashboardStatus()` — berdasarkan kalkulasi kondisi mesin (login, downtime, mould, lot, isi, kuota)
2. `lockInterlock()` di downtime.ino → langsung set LOW saat downtime dimulai (tanpa menunggu kalkulasi)

---

### login.ino

Login dan logout operator. Mengelola autentikasi operator sebelum mesin bisa dijalankan.

**`sendFormattedCommand(format, value)`** — helper untuk kirim perintah format ke HMI. Dua versi: untuk string dan untuk angka.

**`setFrontLogin(id, name)`** — set login depan:
1. `pageSys.frontLogin.val=1` — flag login aktif
2. `pageSys.nFOpId.val={id}` — simpan ID operator
3. `pageSys.tFOpName.txt="{name}"` — simpan nama operator
4. Update kolom nama di halaman login
5. Update dashboard: tampilkan nama operator
6. `updateDashboardStatus()` — status mungkin berubah ke READY
7. `publishBothLayers()` — kirim data ke server (termasuk nama operator)

**`setBackLogin()`** — logika sama untuk layer belakang.

**`clearFrontLogin()`** — logout depan:
1. Set `currentPageId = 0` (kembali ke dashboard)
2. Reset semua field: login=0, ID=0, nama kosong
3. Update kolom nama di dashboard: "Silahkan Login"
4. `updateDashboardStatus()` — status berubah ke LOCKED
5. `publishBothLayers()` — kirim data ke server
6. Kembali ke halaman dashboard

**`clearBackLogin()`** — logika sama.

**`handleFrontLogin()`** — proses login depan:
1. Baca ID dari `nIdF` (kolom input angka)
2. Cari di tabel `OPERATORS` di config.h
3. Jika tidak ditemukan → tampilkan "ID SALAH"
4. Jika ditemukan → panggil `setFrontLogin(id, name)`

**`handleBackLogin()`** — logika sama untuk belakang.

**Callback tombol:**
- `bOkFCallback` → `handleFrontLogin()`
- `bOkBCallback` → `handleBackLogin()`
- `bLogoutFCallback` → `clearFrontLogin()`
- `bLogoutBCallback` → `clearBackLogin()`
- `bBackFCallback` / `bBackBCallback` → set `currentPageId = 0`

**`pageCallback(ptr)`** — dipanggil saat operator pindah halaman. Simpan `currentPageId` dari pointer. Jika masuk halaman simulasi → `syncSimulationTargets()`.

**`registerLoginCallbacks()`** — daftarkan callback untuk semua halaman (pageDashboard, pageLoginF, pageLoginB, dll) dan semua tombol login/logout/back.

---

### publish.ino

Pengiriman data kondisi mesin ke server. Data dikirim dalam format JSON dan disimpan di server (retained).

**`FRONT_COMPONENTS`** / **`BACK_COMPONENTS`** — konstanta berisi nama-nama komponen HMI untuk tiap layer. Contoh: `"pageSys.nFCyc"` untuk siklus depan, `"pageSys.tFModel"` untuk model depan.

**`readLayerState(components, state)`** — baca semua nilai dari HMI untuk satu layer:
1. `memset(state, 0, sizeof(*state))` — kosongkan struct
2. Baca 8 nilai angka: cycle, output, ok, ng, quota, isi, target, operatorId
3. Baca 3 nilai teks: model, lot, operatorName
4. Return true jika semua berhasil dibaca

**`publishLayerState(topic, components)`** — publish data satu layer ke server:
1. Cek MQTT connected
2. `readLayerState()` — baca semua nilai dari HMI
3. Buat `JsonDocument` (ArduinoJson v7)
4. Isi semua field: cycle, output, ok, ng, quota, isi, target, model, lot, operator, operator_id, startTime, finishTime
5. Serialize ke buffer 384 byte
6. `mqttClient.publish(topic, payload, true)` — publish retained

Retained artinya server menyimpan pesan terakhir. Subscriber yang baru connect akan langsung terima data terakhir tanpa menunggu publish baru.

**`publishBothLayers()`** — panggil `publishLayerState()` untuk depan (`DATA_A_TOPIC`) dan belakang (`DATA_B_TOPIC`).

---

### rtc.ino

Sumber waktu. Mendukung dua mode: NTP (internet) dan RTC (jam hardware). Hanya satu mode aktif, diatur di `config.h`.

**Variabel NTP:**
- `ntpConfigured` — apakah sudah pernah jalankan `configTzTime()` (cukup sekali)
- `ntpReady` — apakah waktu dari NTP sudah berhasil diambil
- `lastNtpAttempt` — kapan terakhir coba ambil waktu
- `NTP_RETRY_INTERVAL` — interval retry 1 detik

**Variabel RTC:**
- `rtc` — objek `RTC_DS3231` untuk komunikasi I2C
- `rtcReady` — apakah modul RTC terdeteksi

**Variabel umum:**
- `lastRtcUpdate` — kapan terakhir update `tNow` di HMI
- `RTC_UPDATE_INTERVAL` — interval update 1 detik

**`sendRtcText(value)`** — kirim timestamp ke `pageSys.tNow.txt` di HMI.

**`initTimeSource()`** — inisialisasi sumber waktu:
- **NTP mode**: `setenv("TZ", WIB_TIMEZONE, 1)` + `tzset()` → set zona waktu WIB. Tidak perlu internet.
- **RTC mode**: `Wire.begin()` → mulai I2C. `rtc.begin()` → deteksi modul. Jika `rtc.lostPower()` → set waktu dari compiled time. Set `rtcReady = true`.

**`syncTimeSource()`** — sinkronisasi waktu:
- **NTP mode**: skip jika sudah ready, WiFi belum nyambung, atau belum lewat 1 detik. Jalankan `configTzTime()` sekali pertama. Coba `getLocalTime()`. Jika berhasil → `ntpReady = true`.
- **RTC mode**: tidak perlu sinkronisasi (selalu tersedia).

**`getCurrentTimestamp(buffer, length)`** — ambil waktu saat ini:
- **NTP mode**: jika belum ready → return `"0000-00-00 00:00:00"`. Format: `YYYY-MM-DD HH:MM:SS`.
- **RTC mode**: jika belum ready → return `"0000-00-00 00:00:00"`. Format: `YYYY-MM-DD HH:MM:SS`.

**`updateTnow()`** — update timestamp di HMI tiap 1 detik:
1. Cek sudah lewat 1 detik sejak update terakhir
2. Ambil timestamp dari `getCurrentTimestamp()`
3. Kirim ke `pageSys.tNow.txt`

Firmware HANYA mengupdate `pageSys.tNow.txt`. Jam di dashboard (`tHH/tMM/tSS`) dikendalikan oleh HMI sendiri via timer internal.

---

### scanner.ino

Input dari barcode scanner via Serial2.

**Variabel:**
- `scannerBuffer[32]` — buffer sementara untuk menyimpan karakter yang masuk
- `scannerIdx` — indeks karakter terakhir di buffer

**`processScannerInput(input)`** — proses data dari scanner berdasarkan halaman aktif:

| `currentPageId` | Fungsi dipanggil |
|---|---|
| `PAGE_MLD_F_ID` | `fillFrontMouldInput(input)` |
| `PAGE_MLD_B_ID` | `fillBackMouldInput(input)` |
| `PAGE_LOT_F_ID` | `fillFrontLotInput(input)` |
| `PAGE_LOT_B_ID` | `fillBackLotInput(input)` |
| `PAGE_LOGIN_F_ID` | `nIdF.setValue(id)` — konversi string ke angka |
| `PAGE_LOGIN_B_ID` | `nIdB.setValue(id)` — konversi string ke angka |

**`handleScanner()`** — baca karakter dari Serial2 satu per satu:
1. Jika karakter `\n` atau `\r` → proses data yang terkumpul, reset buffer
2. Jika bukan newline → tambahkan ke buffer (maks 32 karakter)

---

### simulation.ino

Mode simulasi otomatis untuk testing tanpa mesin asli. Juga berisi display helpers untuk update angka di layar.

**Variabel:**
- `autoFrontEnabled` / `autoBackEnabled` — apakah auto-cycle aktif untuk tiap layer
- `autoFrontIntervalMs` / `autoBackIntervalMs` — interval auto-cycle dalam milidetik
- `autoFrontLastCycleAt` / `autoBackLastCycleAt` — timestamp siklus terakhir

**Display helpers:**

**`updateFrontSimulationDisplay(cycle, output, quota, isi, ng, ok)`** — update 6 angka di halaman simulasi: `nSCycF`, `nSOutF`, `nSQuotaF`, `nSIsiF`, `nSNGF`, `nSOKF`.

**`updateFrontDashboardDisplay(cycle, output, isi, ok)`** — update 4 angka di dashboard: `nFCycD`, `nFOutD`, `nFOutD2` (OK), `nFIsiD`.

**`updateBackSimulationDisplay()`** / **`updateBackDashboardDisplay()`** — logika sama untuk layer belakang.

**Auto-cycle:**

**`bAutoEnFCallback()`** — tombol enable auto-cycle depan ditekan:
1. Baca interval dari `nAutoMsF` (milidetik)
2. Jika interval 0 → disable, tampilkan "AUTO F MS 0"
3. Jika interval valid → catat waktu mulai, enable auto-cycle

**`bAutoDisFCallback()`** — disable auto-cycle depan.

**`bAutoEnBCallback()`** / **`bAutoDisBCallback()`** — logika sama untuk belakang.

**`runAutoFrontCycle()`** — jalankan satu siklus otomatis untuk depan:
1. Baca semua nilai dari HMI: ready, siklus, output, kuota, isi, NG
2. Jika gagal baca → disable auto, tampilkan "AUTO F READ NG"
3. Jika `ready==0` → disable, "AUTO F MESIN LOCK"
4. Jika `isi==0` → disable, "AUTO F ISI 0"
5. Jika `quota < isi` → disable, "AUTO F KUOTA KURANG"
6. Jika semua OK → increment siklus, output, kurangi kuota, update semua display

**`runAutoBackCycle()`** — logika sama untuk belakang.

**`updateSimulation()`** — dipanggil dari `loop()`. Cek timer untuk kedua layer. Jika waktunya → jalankan auto-cycle.

**`registerSimulationCallbacks()`** — daftarkan callback tombol auto enable/disable.

---

## Topik MQTT

| Topik | Arah | Disimpan | Isi |
|---|---|---|-----|
| `start/IOTHP-BP/...` | Simulator → Firmware | Tidak | `"START"` |
| `finish/IOTHP-BP/...` | Simulator → Firmware | Tidak | JSON siklus |
| `dataA/IOTHP-BP/...` | Firmware → Server | Ya | Data layer depan |
| `dataB/IOTHP-BP/...` | Firmware → Server | Ya | Data layer belakang |
| `event/IOTHP-BP/...` | Firmware → Server | Tidak | Event downtime/NG |
| `CONTROL/IOTHP-BP/...` | Server → Firmware | — | `"REBOOT"` |

## GPIO (Pin ESP32)

| Pin | Fungsi | Arah |
|-----|---|---|
| GPIO25 | Pengaman (interlock) | OUTPUT (HIGH=siap, LOW=lock) |
| GPIO16 | Scanner barcode RX | INPUT |
| GPIO17 | Scanner barcode TX | OUTPUT |

## Troubleshooting

| Masalah | Solusi |
|---|---|
| Interlock merah | Cek login, mould, lot, isi, kuota |
| Siklus tidak bertambah | Pastikan interlock hijau, isi>0, kuota≥isi |
| Waktu salah | Pastikan WiFi dan internet aktif |
| Data tidak muncul di server | Cek koneksi WiFi, restart jika perlu |
| Barcode tidak terbaca | Cek kabel Serial2, baud rate 9600 |

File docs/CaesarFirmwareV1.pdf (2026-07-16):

# CaesarFirmwareV1

Firmware ESP32 yang mengontrol mesin cetak Caesar. Semua operasi — login operator, input mould, input lot, pencacahan siklus, pencatatan waktu henti, pencatatan produk cacat, hingga pengiriman data ke server — berjalan dari firmware ini.

# Cara Kerja

┌──────────────┐ | ┌──────────────┐
│ | OPERATOR | │─────▶│ MESIN CETAK │
│ (di layar) │ | │ (bergerak) │
└──────┬───────┘ | └──────┬───────┘
| │ | │
| ▼ | ▼
┌──────────────┐ | ┌──────────────┐
│ HMI Nextion │◀────▶│ ESP32 | │
│ (layar sentuh)│ | │ (otak system)│
└──────────────┘ | └──────┬───────┘
| | │
| | ▼
| | ┌──────────────┐
| | │ MQTT Broker │
│ (server) | │
| | └──────────────┘

Simulator kirim sinyal START. Firmware hitung 5 gerakan naik-turun. Simulator kirim sinyal siklus selesai. Firmware tambah jumlah siklus, kurangi kuota, update layar, kirim data ke server.

# Fitur

Bagian | Fungsi
Login | Operator login sebelum jalankan mesin
Mould | Input cetakan (model, jumlah lubang)
Lot | Input nomor lot dan target produksi
Siklus | Hitung berapa kali mesin mencetak

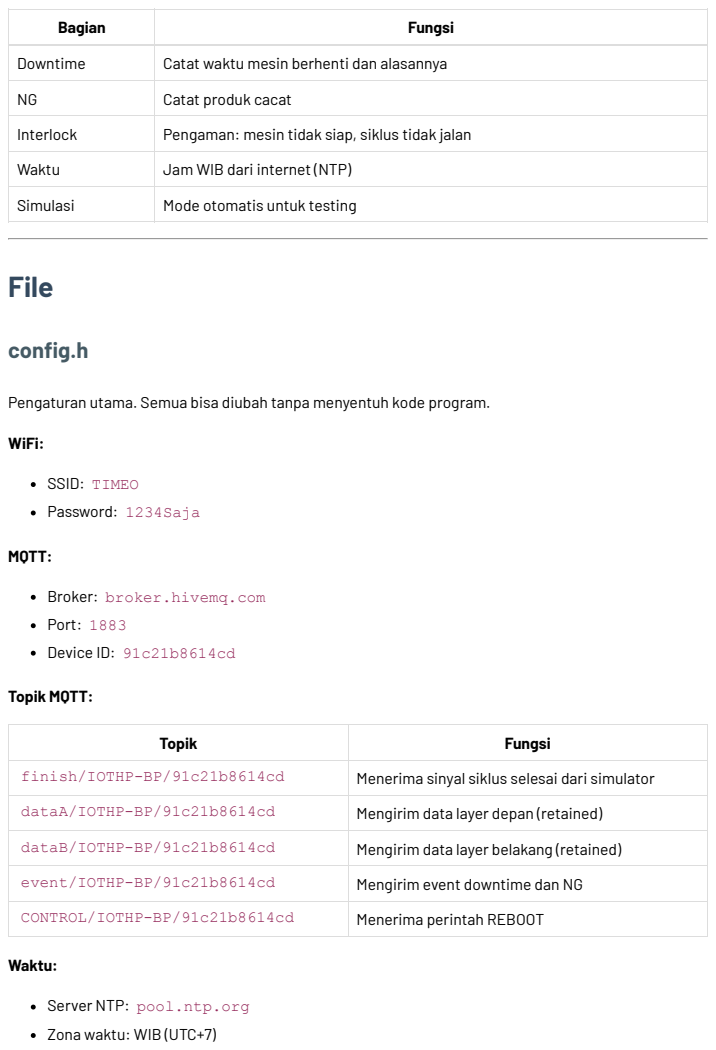
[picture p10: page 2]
File; config.h; WiFi:; SSID: TIMEO; Password: 1234Saja; MQTT:; Topik MQTT:; Waktu:

Bagian | Fungsi

Downtime | Catat waktu mesin berhenti dan alasannya
NG | Catat produk cacat
Interlock | Pengaman: mesin tidak siap, siklus tidak jalan
Waktu | Jam WIB dari internet (NTP)
Simulasi | Mode otomatis untuk testing

Pengaturan utama. Semua bisa diubah tanpa menyentuh kode program.

Broker: broker.hivemq.com
Port: 1883
Device ID: 91c21b8614cd

Topik | Fungsi

finish/IOTHP-BP/91c21b8614cd | Menerima sinyal siklus selesai dari simulator
dataA/IOTHP-BP/91c21b8614cd | Mengirim data layer depan (retained)
dataB/IOTHP-BP/91c21b8614cd | Mengirim data layer belakang (retained)

event/IOTHP-BP/91c21b8614cd | Mengirim event downtime dan NG

CONTROL/IOTHP-BP/91c21b8614cd | Menerima perintah REBOOT

Server NTP: pool.ntp.org
Zona waktu: WIB (UTC+7)

Tabel Data:

Tabel | Isi
Operator | ID 1111-3333, nama lengkap
Mould | Kode 1111-3333, nama model, jumlah cavity
Lot | Kode 1111-3333, nama model, target produksi

Edit tabel di config.h sesuai data produksi aktual.

## CaesarFirmwareV1.ino

File utama yang menghubungkan semua bagian. Berisi deklarasi komponen HMI, variabel global, dan alur utama program.

Variabel global:

WiFiClient wifiClient — objek koneksi WiFi
PubSubClient mqttClient — objek koneksi MQTT, pakai wifiClient sebagai transport char cycleStartTime[32] / char cycleFinishTime[32] — menyimpan waktu mulai dan selesai siklus terakhir dari simulator
LayerComponents — struct berisi nama-nama komponen di HMI untuk tiap layer (cycle, output, ok, ng, quota, isi, target, model, lot, operatorName, operatorId)
LayerState — struct berisi nilai produksi aktual untuk satu layer
uint8_t currentPageId — nomor halaman HMI yang sedang aktif. Scanner membaca nilai ini untuk tahu harus kirim input ke mana.

Deklarasi komponen HMI:
Semua halaman ( NexPage ), tombol ( NexButton ), teks ( NexText ), angka ( NexNumber ), dan variabel ( NexVariable ) dideklarasikan di sini. Setiap komponen punya nomor halaman, nomor komponen, dan nama. Contoh: NexButton bOkF = NexButton(1, 2, "bOkF") artinya tombol "bOkF" di halaman 1, komponen nomor 2.

nex_listen_list — array semua komponen yang harus didengarkan. nexLoop(nex_listen_list) di loop() akan memeriksa apakah ada tombol yang ditekan operator.

setup() — dijalankan sekali saat ESP32 dinyalakan:

1. Serial.begin(115200) — nyalakan serial monitor untuk debug

2. SCANNER_SERIAL.begin(...) — nyalakan Serial2 untuk barcode scanner (RX=GPIO16, TX=GPIO17, 9600 baud)
3. initTimeSource() — set zona waktu WIB atau inisialisasi modul RTC
4. initInterlock() — set GPIO25 sebagai OUTPUT, matikan dulu (LOW)
5. registerLoginCallbacks() — daftarkan semua callback tombol login, logout, dan navigasi

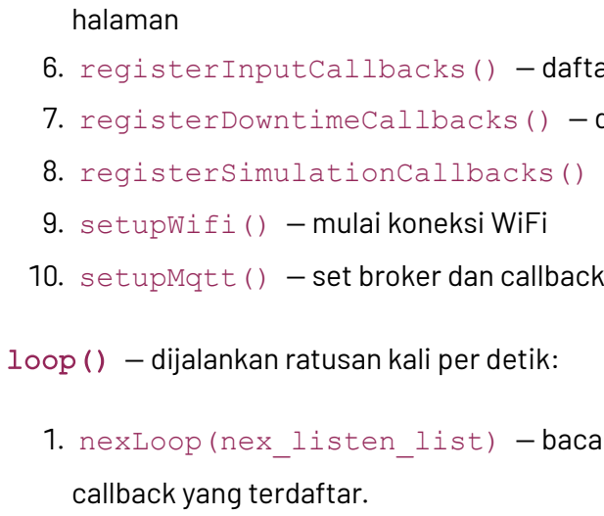
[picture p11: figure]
halaman; 9. setupWifi() — mulai koneksi WiFi; callback yang terdaftar.

6. registerInputCallbacks() — daftarkan callback tombol mould, lot, dan NG submit
7. registerDowntimeCallbacks() — daftarkan callback tombol downtime (mulai dan clear)
8. registerSimulationCallbacks() — daftarkan callback tombol auto-cycle
10. setupMqtt() — set broker dan callback MQTT

loop() — dijalankan ratusan kali per detik:

1. nexLoop(nex_listen_list) — baca semua tombol di HMI. Jika ada yang ditekan, panggil
2. mqttLoop() — proses koneksi WiFi, MQTT, dan pesan masuk
3. syncTimeSource() — ambil waktu dari NTP jika belum sinkron
4. handleScanner() — baca input dari barcode scanner
5. updateTnow() — kirim timestamp lengkap ke pageSys.tNow.txt tiap 1 detik
6. updateSimulation() — jalankan auto-cycle jika mode simulasi aktif

## wifi_mqtt.ino

Mengatur koneksi WiFi dan MQTT. Semua komunikasi dengan server melewati file ini.

Variabel global:

lastWifiAttempt — timestamp kapan terakhir coba sambung WiFi. Digunakan untuk delay 5 detik agar ESP32 tidak spam reconnect.
lastMqttAttempt — timestamp kapan terakhir coba sambung MQTT. Delay sama, 5 detik.

publishEvent(json) — kirim event ke server (downtime/NG). Cek MQTT connected dulu. Publish non-retained ke EVENT_TOPIC . Non-retained artinya pesan tidak disimpan server — jika subscriber offline saat pesan dikirim, subscriber tidak akan terima pesan ini nanti.

mqttCallback(topic, payload, length) — handler saat terima pesan dari server. Dua jenis pesan yang dihandle:

1. Dari CONTROL_TOPIC , isi REBOOT (6 karakter) → restart ESP32 via ESP.restart()

2. Dari FINISH_TOPIC , isi JSON 1cycle → parse JSON, ambil startTime dan finishTime , panggil handleMqttCycle()

Jika pesan bukan dari kedua topik ini → diabaikan.

setupWifi() — set WiFi mode sebagai station (bukan access point), set hostname ke MQTT_CLIENT_ID agar mudah dikenali di jaringan, mulai koneksi ke SSID dan password yang ditentukan.

setupMqtt() — set alamat broker dan port, daftarkan mqttCallback untuk pesan masuk, set buffer 256 byte (cukup untuk payload JSON siklus), set keep alive 60 detik (jika tidak ada aktivitas MQTT selama 60 detik, koneksi putus otomatis), set socket timeout 5 detik.

reconnectWifi() — jika WiFi sudah terhubung → skip. Jika belum dan sudah lewat 5 detik sejak percobaan terakhir → putuskan WiFi lalu sambung ulang. Delay 5 detik mencegah ESP32 mencoba sambung ulang terlalu sering.

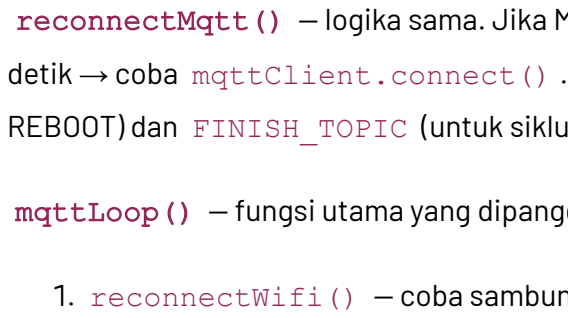
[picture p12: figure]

reconnectMqtt() — logika sama. Jika MQTT sudah terhubung → skip. Jika belum dan sudah lewat 5 detik → coba mqttClient.connect() . Setelah terhubung → subscribe CONTROL_TOPIC (untuk REBOOT) dan FINISH_TOPIC (untuk siklus dari simulator).

mqttLoop() — fungsi utama yang dipanggil dari loop() . Urutan:

1. reconnectWifi() — coba sambung WiFi jika perlu
2. Set LED WiFi: HIGH jika terhubung, LOW jika putus
3. Jika WiFi belum terhubung → skip (tidak bisa proses MQTT tanpa WiFi)
4. reconnectMqtt() — coba sambung MQTT jika perlu
5. Jika MQTT terhubung → mqttLoop() untuk proses pesan masuk

## cycle.ino

Penghitung siklus dari simulator. Dipanggil saat firmware terima JSON 1cycle dari FINISH_TOPIC .

Variabel state:

frontCycle / backCycle — jumlah siklus untuk layer depan dan belakang
frontOutput / backOutput — jumlah output untuk tiap layer frontQuota / backQuota — sisa kuota produksi
frontIsi / backIsi — isi per cetakan (dari mould)
frontNg / backNg — jumlah produk cacat

handleMqttCycle(startTime, finishTime) — fungsi utama. Alur:

1. Baca pageSys.nMReady dari HMI. Jika 0 → interlock merah, siklus tidak jalan. Return.
2. Baca 11 nilai dari HMI: siklus, output, kuota, isi, NG untuk depan dan belakang. Jika gagal baca → return.
3. Cek kondisi: jika frontIsi==0 atau backIsi==0 → mould belum diisi. Jika frontQuota < frontIsi atau backQuota < backIsi → kuota habis. Dalam kedua kasus → update status

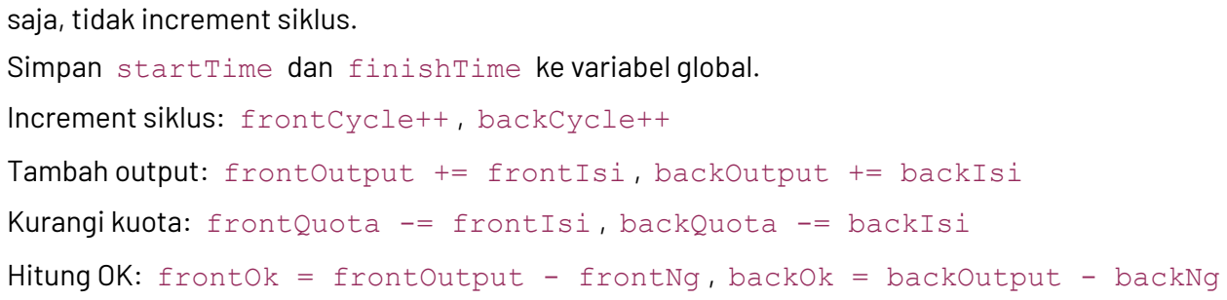
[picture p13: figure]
saja, tidak increment siklus.

4. Simpan startTime dan finishTime ke variabel global.
5. Increment siklus: frontCycle++ , backCycle++
6. Tambah output: frontOutput += frontIsi , backOutput += backIsi
7. Kurangi kuota: frontQuota -= frontIsi , backQuota -= backIsi
8. Hitung OK: frontOk = frontOutput - frontNg , backOk = backOutput - backNg
9. Update semua komponen HMI: siklus, output, kuota, OK untuk depan dan belakang
10. Update tampilan simulation dan dashboard
11. Update dashboard NG display
12. updateDashboardStatus() — hitung ulang status mesin (mungkin berubah karena kuota berkurang)
13. publishBothLayers() — kirim data lengkap ke server (retained)

Siklus selalu increment kedua layer sekaligus. Firmware tidak membedakan layer depan atau belakang dalam siklus.

## dashboard.ino

Logika status mesin. Menentukan apakah mesin siap atau terkunci berdasarkan kondisi saat ini.

isi) — cek kondisi secara berurutan (prioritas dari atas):

1. login == 0 → "BP DEPAN LOCKED" (operator belum login)
2. machineDowntime != 0 → "BP DEPAN MC DOWNTIME" (mesin sedang downtime)
3. downtime != 0 → "BP DEPAN DOWNTIME" (layer ini sedang downtime)
4. quota < isi → "BP DEPAN NO LOT" (kuota kurang dari isi per cetakan)
5. cavity == 0 → "BP DEPAN NO MOULD" (belum pilih mould)
6. isi == 0 → "BP DEPAN ISI 0" (isi per cetakan kosong)
7. Sisanya → "BP DEPAN READY"

getBackDashboardStatus() — logika sama untuk layer belakang.

updateDashboardStatus() — fungsi utama yang dipanggil dari banyak tempat:

1. Baca 11 nilai dari HMI: login depan/belakang, downtime mesin, downtime depan/belakang, kuota depan/belakang, cavity depan/belakang, isi depan/belakang
2. Jika gagal baca → set interlock LOW (fail-safe), return
3. Hitung status untuk depan dan belakang
4. Cek apakah keduanya READY → machineReady
5. Kirim status teks ke dashboard: tFStat , tBStat
6. Set nFReady , nBReady , nMReady di HMI
7. Set warna tILock : hijau (2024) jika siap, merah (63488) jika tidak
8. Kosongkan teks tILock
9. setInterlock(machineReady) — drive GPIO25 sesuai kondisi

syncSimulationTargets() — baca target dari pageSys.nFTarget / nBTarget , kirim ke pageSim.nSTgtF / nSTgtB . Dipanggil saat operator buka halaman simulasi.

## downtime.ino

Pencatatan waktu henti mesin. Mengelola mulai dan clear downtime untuk layer depan, belakang, dan mesin.

sendDowntimeText(format, value) — helper untuk kirim perintah format ke HMI. Contoh:

showDowntimeInfo(pageName) — navigasi ke halaman info downtime:

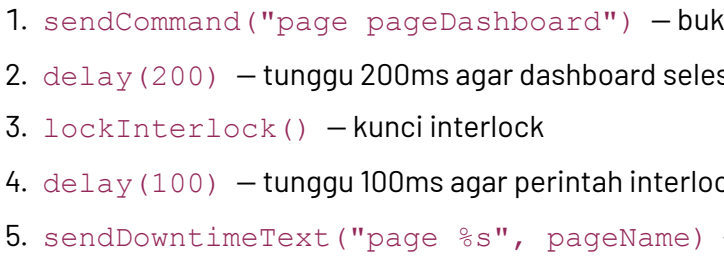
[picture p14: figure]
3. lockInterlock() — kunci interlock

1. sendCommand("page pageDashboard") — buka dashboard dulu
2. delay(200) — tunggu 200ms agar dashboard selesai render
4. delay(100) — tunggu 100ms agar perintah interlock sampai
5. sendDowntimeText("page %s", pageName) — buka halaman info downtime

Dashboard harus muncul dulu karena komponen tILock ada di halaman dashboard. Jika langsung kirim perintah interlock saat masih di halaman downtime, perintah tidak sampai.

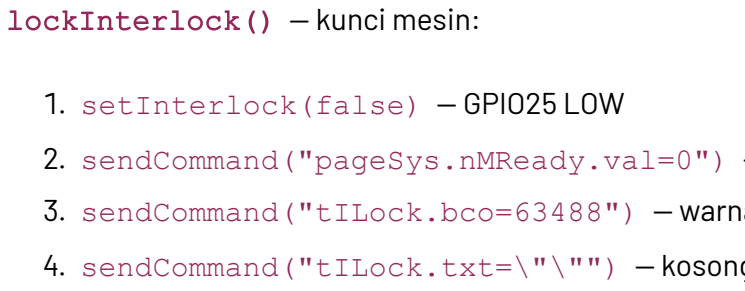
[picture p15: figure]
lockInterlock() — kunci mesin:; 1. setInterlock(false) — GPIO25 LOW

2. sendCommand("pageSys.nMReady.val=0") — set mesin tidak siap
3. sendCommand("tILock.bco=63488") — warna interlock merah
4. sendCommand("tILock.txt=\"\"") — kosongkan teks interlock

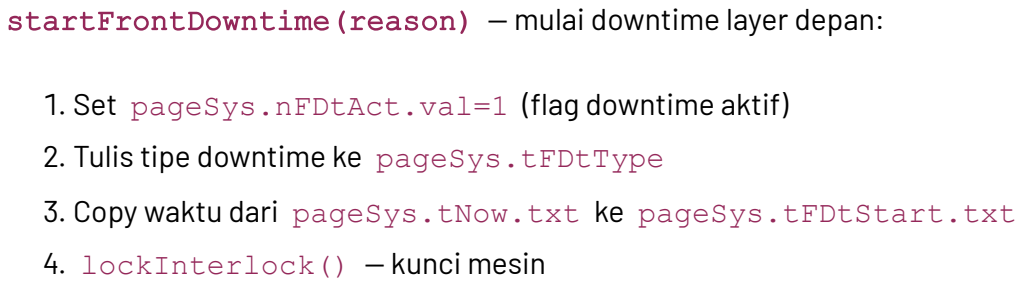
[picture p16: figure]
4. lockInterlock() — kunci mesin

startFrontDowntime(reason) — mulai downtime layer depan:

1. Set pageSys.nFDtAct.val=1 (flag downtime aktif)
2. Tulis tipe downtime ke pageSys.tFDtType
3. Copy waktu dari pageSys.tNow.txt ke pageSys.tFDtStart.txt
5. Ambil timestamp dari NTP, buat JSON event, publish ke server

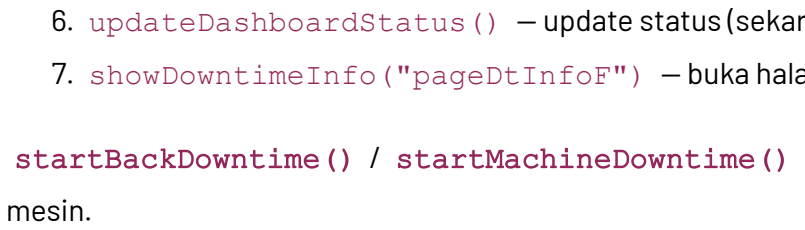
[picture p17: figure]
mesin.

6. updateDashboardStatus() — update status (sekarang DOWNTIME)
7. showDowntimeInfo("pageDtInfoF") — buka halaman info downtime depan

startBackDowntime() / startMachineDowntime() — logika sama untuk layer belakang dan

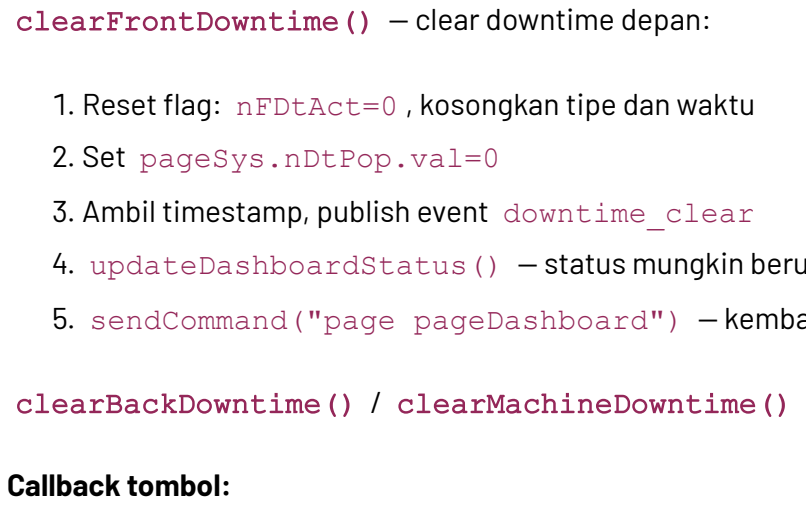
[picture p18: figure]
clearFrontDowntime() — clear downtime depan:; 2. Set pageSys.nDtPop.val=0; Callback tombol:

1. Reset flag: nFDtAct=0 , kosongkan tipe dan waktu
3. Ambil timestamp, publish event downtime_clear
4. updateDashboardStatus() — status mungkin berubah ke READY
5. sendCommand("page pageDashboard") — kembali ke dashboard

clearBackDowntime() / clearMachineDowntime() — logika sama.

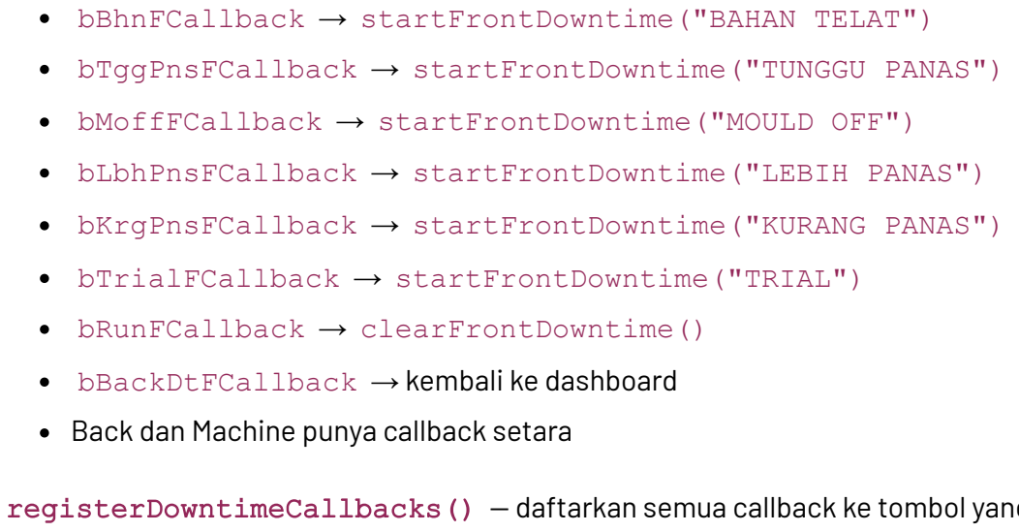
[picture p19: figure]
bBhnFCallback → startFrontDowntime("BAHAN TELAT"); bTggPnsFCallback → startFrontDowntime("TUNGGU PANAS"); bMoffFCallback → startFrontDowntime("MOULD OFF"); bLbhPnsFCallback → startFrontDowntime("LEBIH PANAS"); bKrgPnsFCallback → startFrontDowntime("KURANG PANAS"); bTrialFCallback → startFrontDowntime("TRIAL"); bRunFCallback → clearFrontDowntime() bBackDtFCallback → kembali ke dashboard Back dan Machine punya callback setara

registerDowntimeCallbacks() — daftarkan semua callback ke tombol yang sesuai.

## input.ino

Penerimaan input dari layar HMI dan barcode scanner. File terbesar (469 baris). Berisi semua handler untuk mould, lot, NG, dan helper functions untuk komunikasi dengan HMI.

Komunikasi dasar dengan HMI (Nextion):

sendInputText(component, value) — kirim teks ke komponen HMI. Format: {component}.txt="{value}" . Contoh: sendInputText("pageSys.tFMld", "1111") → kirim pageSys.tFMld.txt="1111" .

sendInputValue(component, value) — kirim angka ke komponen HMI. Format: {component}.val={value} . Contoh: sendInputValue("pageSys.nFCav", 8) → kirim

readNextionText(component, buffer, bufferSize) — baca teks dari HMI. Kirim perintah get {component}.txt . Tunggu jawaban dari HMI (timeout 200ms). Header jawaban: 0x70. Data: karakter biasa. Terminator: 3x 0xFF berturut-turut. Return true jika berhasil.

readNextionValue(component, value) — baca angka dari HMI. Kirim perintah get {component}.val . Header jawaban: 0x71. Data: 4 byte little-endian (nilai angka). Terminator: 3x 0xFF. Return true jika berhasil.

Proses mould:

fillFrontMouldInput(code) — isi kolom input mould depan dengan kode barcode.

handleFrontMould() — proses input mould depan:

1. Baca kode dari tInMF (kolom input)
2. Cari di tabel MOULDS di config.h
3. Jika tidak ditemukan → tampilkan "MOULD NG", set cavity=0, isi=0
4. Jika ditemukan → tampilkan nama model, set cavity dan isi (jumlah lubang), update semua komponen HMI terkait (pageSys, pageLot, pageDashboard, pageSim), update dashboard status, kirim data ke server

clearFrontMould() — kosongkan semua field mould depan, reset cavity dan isi ke 0.

handleBackMould() / clearBackMould() — logika sama untuk layer belakang.

Proses lot:

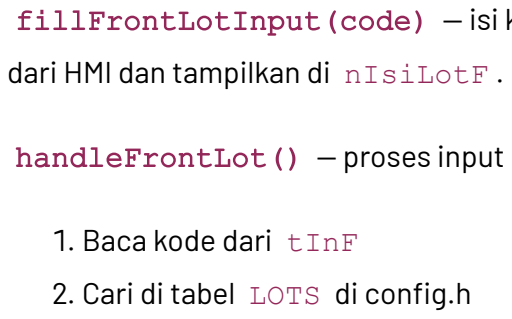
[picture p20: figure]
dari HMI dan tampilkan di nIsiLotF .; 1. Baca kode dari tInF 2. Cari di tabel LOTS di config.h

fillFrontLotInput(code) — isi kolom input lot depan dengan kode barcode. Juga baca cavity

handleFrontLot() — proses input lot depan:

3. Jika tidak ditemukan → tampilkan "LOT NG"
4. Baca cavity dan isi dari HMI. Validasi: cavity harus >0, isi harus >0, isi ≤ cavity
5. Jika semua valid → set target dan kuota, update semua komponen HMI, update dashboard, kirim data ke server

clearFrontLot() — kosongkan semua field lot depan, reset target dan kuota ke 0.

handleBackLot() / clearBackLot() — logika sama untuk layer belakang.

Proses NG:

publishNgEvent(layer, typeComponent, countComponent, acceptedComponent) — kirim event produk cacat:

1. Baca acceptedComponent (flag dari HMI bahwa operator sudah submit). Jika 0 → return.
2. Baca countComponent (jumlah NG). Jika 0 → return.
3. Baca typeComponent (tipe NG, misal "SCRATCH"). Jika kosong → return.
4. Ambil timestamp dari NTP
5. Buat JSON:
6. Publish ke server
7. Clear jumlah NG dan flag submit di HMI

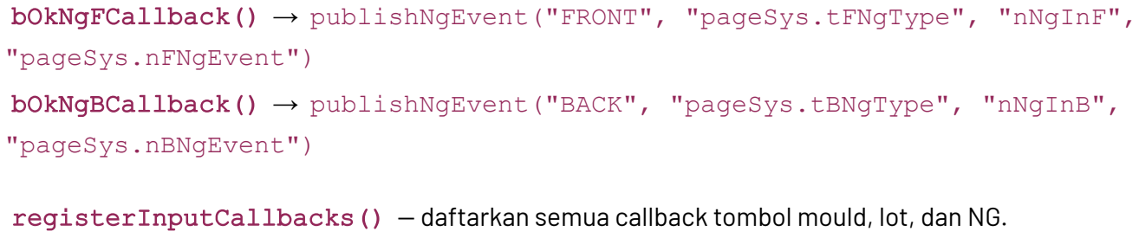
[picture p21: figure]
bOkNgFCallback() → publishNgEvent("FRONT", "pageSys.tFNgType", "nNgInF", "pageSys.nFNgEvent"); bOkNgBCallback() → publishNgEvent("BACK", "pageSys.tBNgType", "nNgInB", "pageSys.nBNgEvent")

registerInputCallbacks() — daftarkan semua callback tombol mould, lot, dan NG.

## interlock.ino

Pengaman mesin via GPIO25. File kecil (10 baris) dengan dua fungsi.

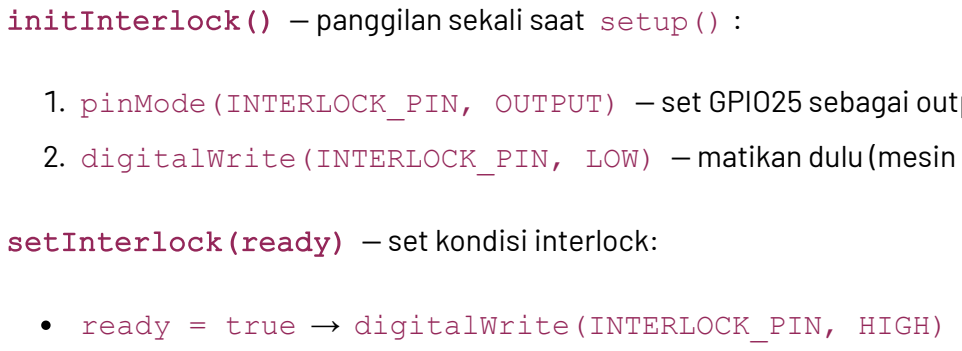
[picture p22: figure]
setInterlock(ready) — set kondisi interlock:

initInterlock() — panggilan sekali saat setup() :

1. pinMode(INTERLOCK_PIN, OUTPUT) — set GPIO25 sebagai output
2. digitalWrite(INTERLOCK_PIN, LOW) — matikan dulu (mesin terkunci saat baru nyala)

ready = true → digitalWrite(INTERLOCK_PIN, HIGH) → mesin siap ready = false → digitalWrite(INTERLOCK_PIN, LOW) → mesin terkunci

Dipanggil dari dua tempat:

1. updateDashboardStatus() — berdasarkan kalkulasi kondisi mesin (login, downtime, mould, lot, isi, kuota)
2. lockInterlock() di downtime.ino → langsung set LOW saat downtime dimulai (tanpa menunggu kalkulasi)

## login.ino

Login dan logout operator. Mengelola autentikasi operator sebelum mesin bisa dijalankan.

sendFormattedCommand(format, value) — helper untuk kirim perintah format ke HMI. Dua versi: untuk string dan untuk angka.

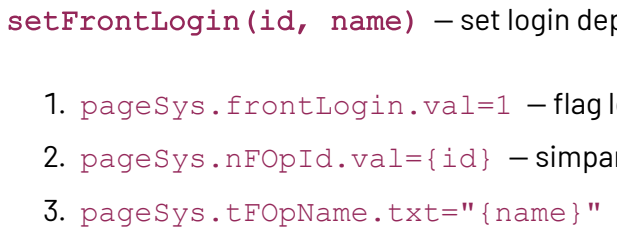
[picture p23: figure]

setFrontLogin(id, name) — set login depan:

1. pageSys.frontLogin.val=1 — flag login aktif
2. pageSys.nFOpId.val={id} — simpan ID operator
3. pageSys.tFOpName.txt="{name}" — simpan nama operator
4. Update kolom nama di halaman login
5. Update dashboard: tampilkan nama operator

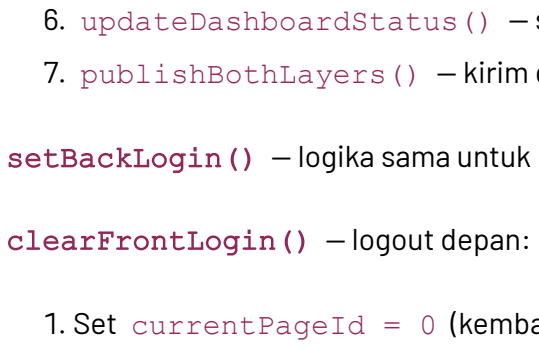
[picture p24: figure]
clearFrontLogin() — logout depan:

6. updateDashboardStatus() — status mungkin berubah ke READY
7. publishBothLayers() — kirim data ke server (termasuk nama operator)

setBackLogin() — logika sama untuk layer belakang.

1. Set currentPageId = 0 (kembali ke dashboard)
2. Reset semua field: login=0, ID=0, nama kosong
3. Update kolom nama di dashboard: "Silahkan Login"
4. updateDashboardStatus() — status berubah ke LOCKED
5. publishBothLayers() — kirim data ke server
6. Kembali ke halaman dashboard

clearBackLogin() — logika sama.

handleFrontLogin() — proses login depan:

1. Baca ID dari nIdF (kolom input angka)

2. Cari di tabel OPERATORS di config.h
3. Jika tidak ditemukan → tampilkan "ID SALAH"
4. Jika ditemukan → panggil setFrontLogin(id, name)

handleBackLogin() — logika sama untuk belakang.

Callback tombol:

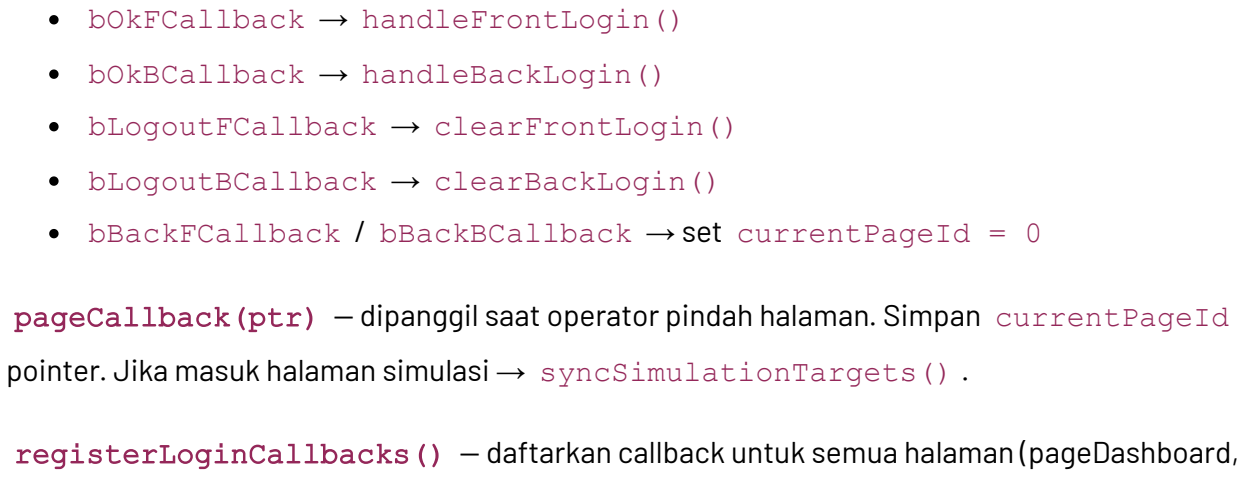
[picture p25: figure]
bOkFCallback → handleFrontLogin(); bOkBCallback → handleBackLogin(); bLogoutFCallback → clearFrontLogin(); bLogoutBCallback → clearBackLogin()

bBackFCallback / bBackBCallback → set currentPageId = 0

pageCallback(ptr) — dipanggil saat operator pindah halaman. Simpan currentPageId dari pointer. Jika masuk halaman simulasi → syncSimulationTargets() .

registerLoginCallbacks() — daftarkan callback untuk semua halaman (pageDashboard, pageLoginF, pageLoginB, dll) dan semua tombol login/logout/back.

## publish.ino

Pengiriman data kondisi mesin ke server. Data dikirim dalam format JSON dan disimpan di server (retained).

FRONT_COMPONENTS / BACK_COMPONENTS — konstanta berisi nama-nama komponen HMI untuk tiap layer. Contoh: "pageSys.nFCyc" untuk siklus depan, "pageSys.tFModel" untuk model depan.

readLayerState(components, state) — baca semua nilai dari HMI untuk satu layer:

1. memset(state, 0, sizeof(*state)) — kosongkan struct
2. Baca 8 nilai angka: cycle, output, ok, ng, quota, isi, target, operatorId
3. Baca 3 nilai teks: model, lot, operatorName
4. Return true jika semua berhasil dibaca

publishLayerState(topic, components) — publish data satu layer ke server:

1. Cek MQTT connected
2. readLayerState() — baca semua nilai dari HMI
3. Buat JsonDocument (ArduinoJson v7)

4. Isi semua field: cycle, output, ok, ng, quota, isi, target, model, lot, operator, operator_id, startTime, finishTime
5. Serialize ke buffer 384 byte
6. mqttClient.publish(topic, payload, true) — publish retained

Retained artinya server menyimpan pesan terakhir. Subscriber yang baru connect akan langsung terima data terakhir tanpa menunggu publish baru.

publishBothLayers() — panggil publishLayerState() untuk depan ( DATA_A_TOPIC ) dan belakang ( DATA_B_TOPIC ).
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

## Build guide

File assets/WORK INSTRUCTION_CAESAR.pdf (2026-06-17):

# WORK INSTRUCTION SHOPFLOOR MODULE HOT PRESS

## 1. TAMPILAN AWAL INTERFACE

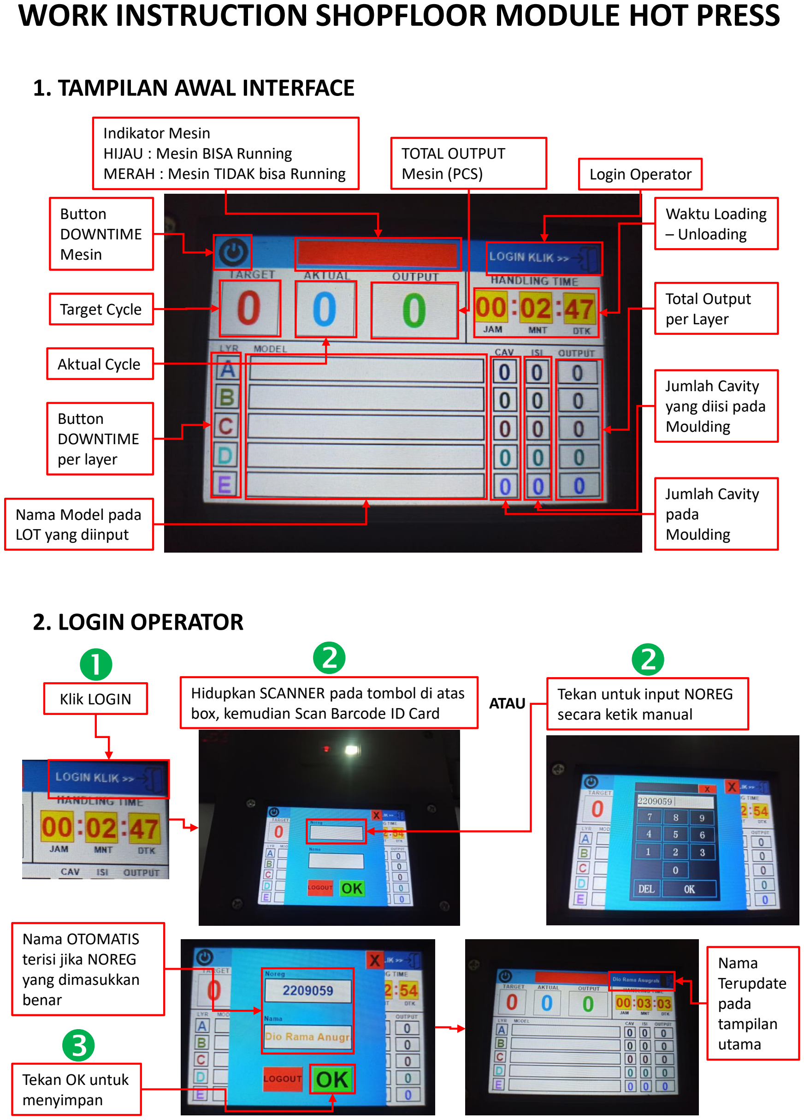
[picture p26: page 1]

Nama OTOMATIS
terisi jika NOREG
yang dimasukkan
benar

Button
DOWNTIME
Mesin

Target Cycle

Aktual Cycle

TOTAL OUTPUT
Mesin (PCS)

Indikator Mesin
HIJAU : Mesin BISA Running
MERAH : Mesin TIDAK bisa Running | Login Operator
| Waktu Loading
| – Unloading

Total Output
per Layer

Jumlah Cavity
yang diisi pada
Moulding

Jumlah Cavity
pada
Moulding

Nama Model pada
LOT yang diinput

Button
DOWNTIME
per layer

## 2. LOGIN OPERATOR

Klik LOGIN | Hidupkan SCANNER pada tombol di atas box, kemudian Scan Barcode ID Card
Tekan untuk input NOREG
secara ketik manual ATAU

Tekan OK untuk
menyimpan

Nama
Terupdate
pada
tampilan
utama

## 3. INPUT MOULDING PER LAYER

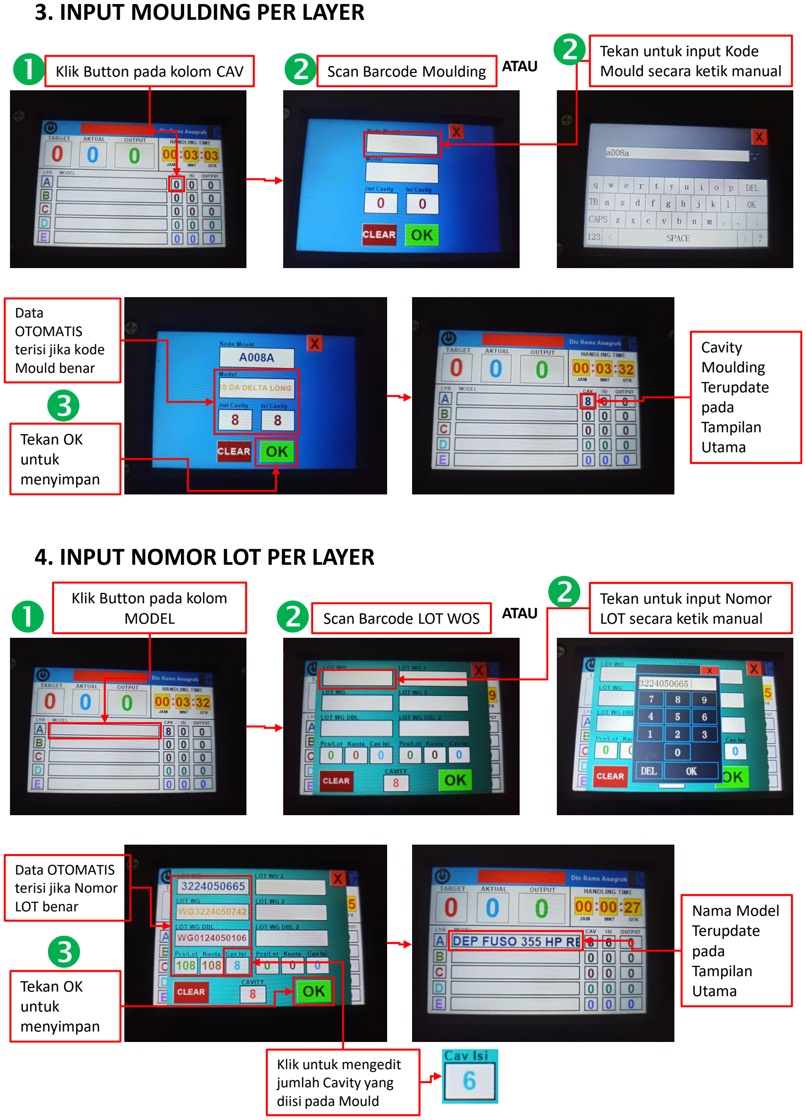
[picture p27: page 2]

## 4. INPUT NOMOR LOT PER LAYER

Klik Button pada kolom CAV | Scan Barcode Moulding

Tekan untuk input Kode

Mould secara ketik manual | | ATAU

Tekan OK
untuk
menyimpan

Cavity
Moulding
Terupdate
pada
Tampilan
Utama

Data
OTOMATIS
terisi jika kode
Mould benar

Klik Button pada kolom
MODEL | Scan Barcode LOT WOS

Tekan untuk input Nomor

LOT secara ketik manual | | ATAU

Tekan OK
untuk
menyimpan

Nama Model
Terupdate
pada
Tampilan
Utama

Data OTOMATIS
terisi jika Nomor
LOT benar

Klik untuk mengedit
jumlah Cavity yang
diisi pada Mould

## 5. KONDISI MESIN BISA RUNNING

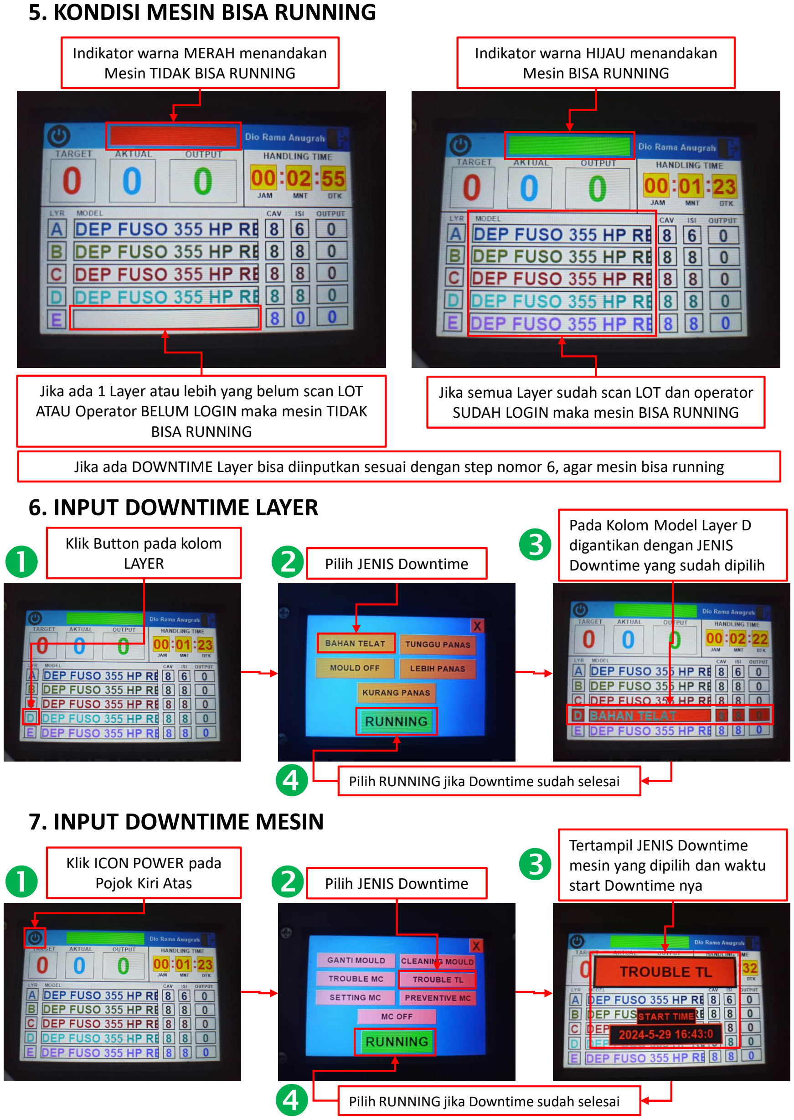
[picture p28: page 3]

## 6. INPUT DOWNTIME LAYER

Klik Button pada kolom | LAYER | | Pilih JENIS Downtime

Pilih RUNNING jika Downtime sudah selesai

Jika ada 1 Layer atau lebih yang belum scan LOT ATAU Operator BELUM LOGIN maka mesin TIDAK BISA RUNNING

Indikator warna MERAH menandakan Mesin TIDAK BISA RUNNING

Indikator warna HIJAU menandakan Mesin BISA RUNNING

Jika semua Layer sudah scan LOT dan operator SUDAH LOGIN maka mesin BISA RUNNING

Jika ada DOWNTIME Layer bisa diinputkan sesuai dengan step nomor 6, agar mesin bisa running

Pada Kolom Model Layer D
digantikan dengan JENIS
Downtime yang sudah dipilih

## 7. INPUT DOWNTIME MESIN

Klik ICON POWER pada | Pojok Kiri Atas | | Pilih JENIS Downtime

Pilih RUNNING jika Downtime sudah selesai

Tertampil JENIS Downtime
mesin yang dipilih dan waktu start Downtime nya

## 8. PROSES PERHITUNGAN CYCLE

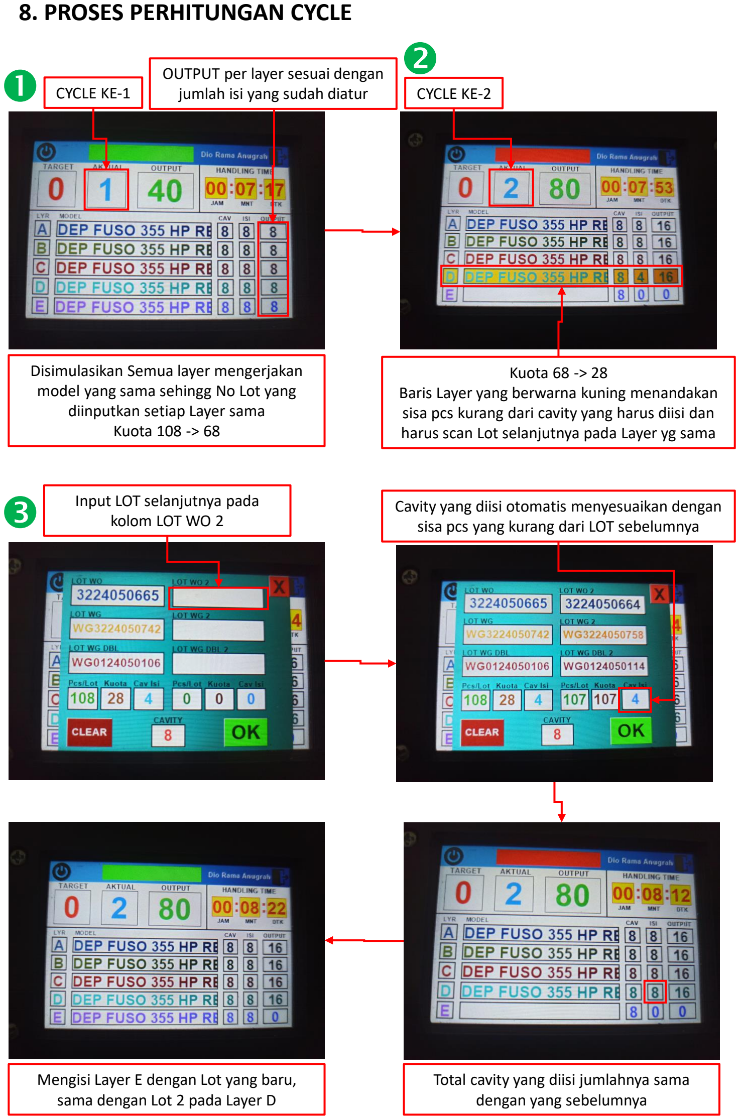
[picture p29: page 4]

Disimulasikan Semua layer mengerjakan model yang sama sehingg No Lot yang diinputkan setiap Layer sama Kuota 108 -> 68

- CYCLE KE-1

OUTPUT per layer sesuai dengan jumlah isi yang sudah diatur

Kuota 68 -> 28
Baris Layer yang berwarna kuning menandakan sisa pcs kurang dari cavity yang harus diisi dan harus scan Lot selanjutnya pada Layer yg sama

CYCLE KE-2

Input LOT selanjutnya pada kolom LOT WO 2

Cavity yang diisi otomatis menyesuaikan dengan sisa pcs yang kurang dari LOT sebelumnya

Total cavity yang diisi jumlahnya sama dengan yang sebelumnya

Mengisi Layer E dengan Lot yang baru, sama dengan Lot 2 pada Layer D

## 8. PROSES PERHITUNGAN CYCLE

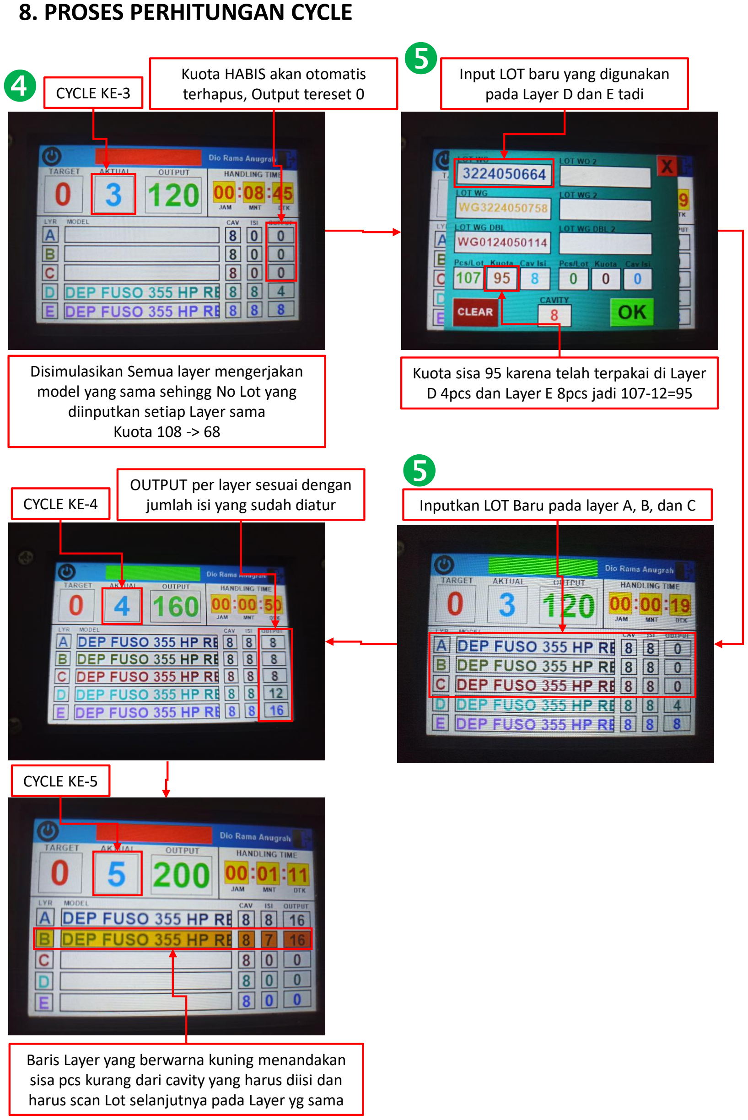
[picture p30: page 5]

Disimulasikan Semua layer mengerjakan model yang sama sehingg No Lot yang diinputkan setiap Layer sama Kuota 108 -> 68

- CYCLE KE-3

Kuota HABIS akan otomatis
terhapus, Output tereset 0

Kuota sisa 95 karena telah terpakai di Layer D 4pcs dan Layer E 8pcs jadi 107-12=95

Input LOT baru yang digunakan pada Layer D dan E tadi

Inputkan LOT Baru pada layer A, B, dan C

CYCLE KE-4

OUTPUT per layer sesuai dengan jumlah isi yang sudah diatur

Baris Layer yang berwarna kuning menandakan sisa pcs kurang dari cavity yang harus diisi dan harus scan Lot selanjutnya pada Layer yg sama

CYCLE KE-5

## 9. INPUT HASIL NG

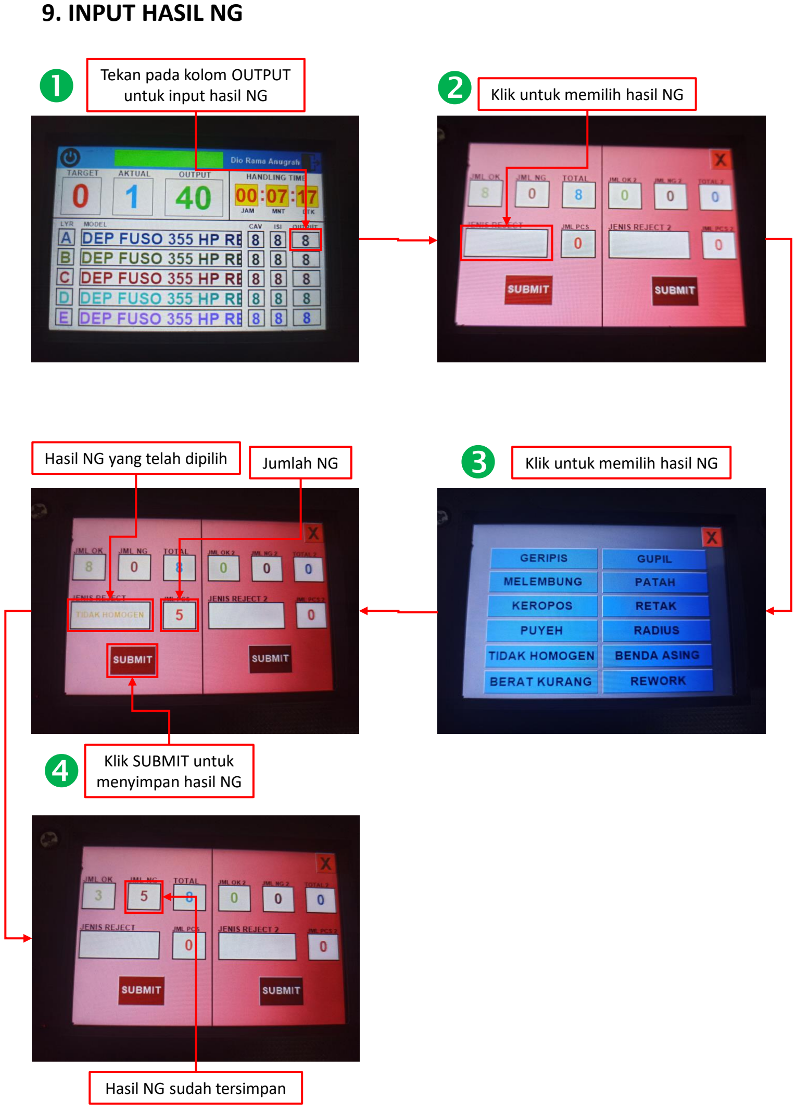
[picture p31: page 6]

Tekan pada kolom OUTPUT
untuk input hasil NG | | Klik untuk memilih hasil NG
Hasil NG yang telah dipilih | Jumlah NG | | Klik untuk memilih hasil NG

Hasil NG sudah tersimpan

Klik SUBMIT untuk
menyimpan hasil NG

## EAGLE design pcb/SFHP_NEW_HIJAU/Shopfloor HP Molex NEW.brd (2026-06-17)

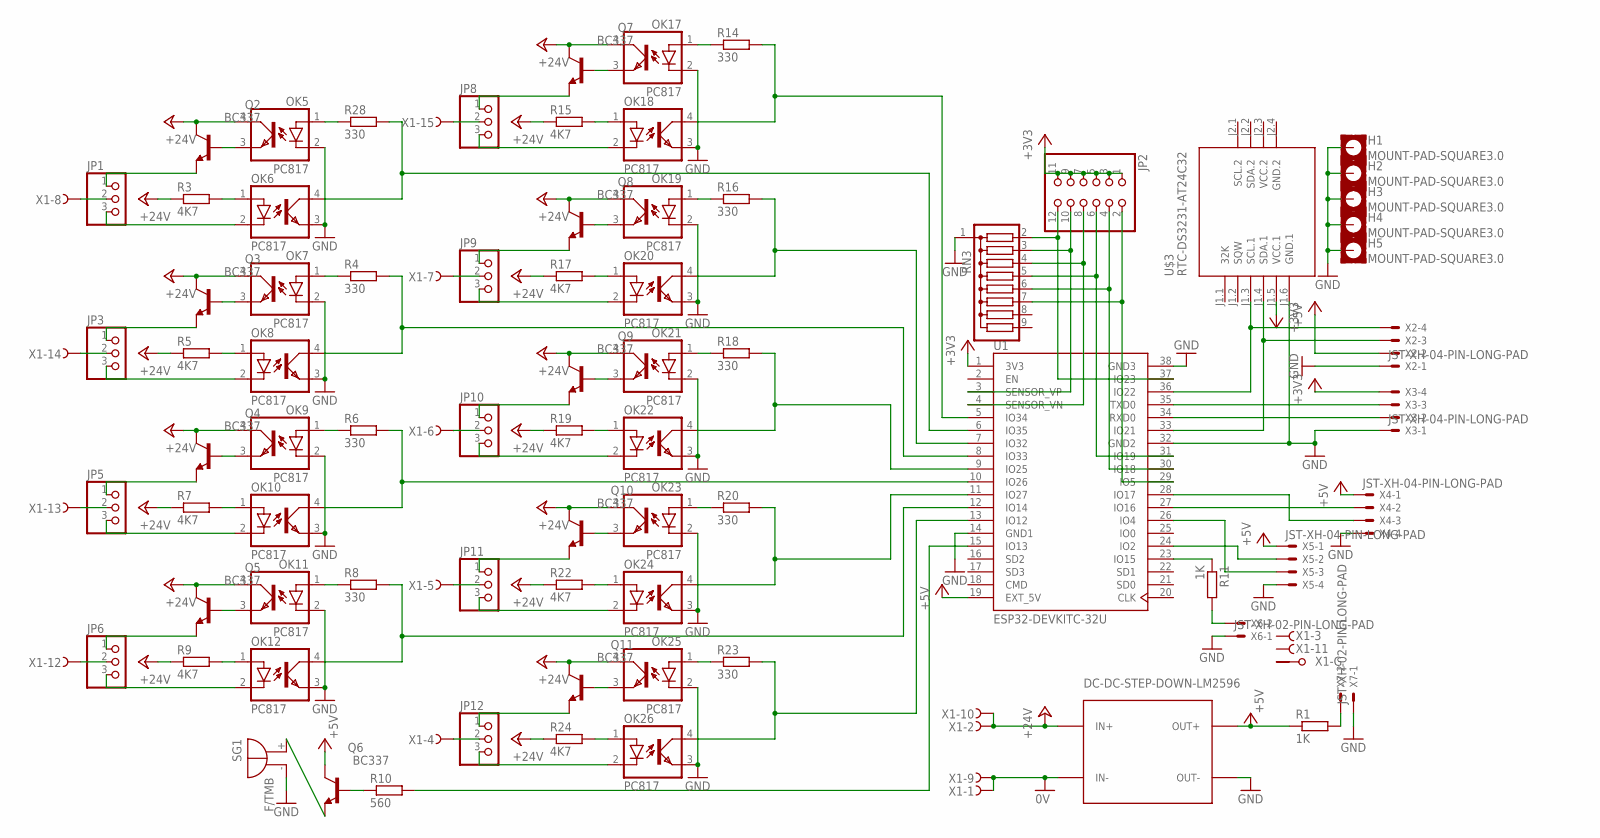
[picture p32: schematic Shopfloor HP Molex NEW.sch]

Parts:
H1, H2, H3, H4, H5: MOUNT-PAD-SQUARE3.0; 3,0-PAD-SQUARE
JP1, JP3, JP5, JP6, JP8, JP9, JP10, JP11, JP12: PINHD-1X3; 1X03
JP2: PINHD-2X6; 2X06
OK5, OK6, OK7, OK8, OK9, OK10, OK11, OK12, OK17, OK18, OK19, OK20, OK21, OK22, OK23, OK24, OK25, OK26: PC817; DIL04
Q2, Q3, Q4, Q5, Q6, Q7, Q8, Q9, Q10, Q11: BC337; TO92
R1, R11: 1K; 0207/7
R3, R5, R7, R9, R15, R17, R19, R22, R24: 4K7; 0207/7
R4, R6, R8, R14, R16, R18, R20, R23, R28: 330; 0207/7
R10: 560; 0207/7
RN3: G08R; SIL9
SG1: F/TMB
U1: ESP32-DEVKITC-32U; MODULE_ESP32-DEVKITC-32U
U$1: DC-DC-STEP-DOWN-LM2596
U$3: RTC-DS3231-AT24C32
X1: F15HPS; F15HP
X2, X3, X4, X5: JST-XH-04-PIN-LONG-PAD; JST-XH-04-PACKAGE-LONG-PAD
X6, X7: JST-XH-02-PIN-LONG-PAD; JST-XH-02-PACKAGE-LONG-PAD

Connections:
0V: U$1.IN-, X1.1 (F), X1.9 (F)
+3V3: JP2.1, JP2.3, JP2.5, JP2.7, JP2.9, JP2.11, U1.1 (3V3), U$3.J1.5 (VCC.1), X3.4
+5V: Q6.3 (C), R1.1, U1.19 (EXT_5V), U$1.OUT+, X2.2, X4.1, X5.1
+24V: OK5.4 (COL), OK7.4 (COL), OK9.4 (COL), OK11.4 (COL), OK17.4 (COL), OK19.4 (COL), OK21.4 (COL), OK23.4 (COL), OK25.4 (COL), Q2.3 (C), Q3.3 (C), Q4.3 (C), Q5.3 (C), Q7.3 (C), Q8.3 (C), Q9.3 (C), Q10.3 (C), Q11.3 (C), R3.1, R5.1, R7.1, R9.1, R15.1, R17.1, R19.1, R22.1, R24.1, U$1.IN+, X1.2 (F), X1.10 (F)
GND: H1.B3,0, H2.B3,0, H3.B3,0, H4.B3,0, H5.B3,0, OK5.2 (C), OK6.3 (EMIT), OK7.2 (C), OK8.3 (EMIT), OK9.2 (C), OK10.3 (EMIT), OK11.2 (C), OK12.3 (EMIT), OK17.2 (C), OK18.3 (EMIT), OK19.2 (C), OK20.3 (EMIT), OK21.2 (C), OK22.3 (EMIT), OK23.2 (C), OK24.3 (EMIT), OK25.2 (C), OK26.3 (EMIT), RN3.1, SG1.-, U1.14 (GND1), U1.32 (GND2), U1.38 (GND3), U$1.OUT-, U$3.J1.6 (GND.1), X2.1, X3.1, X4.4, X5.4, X6.1, X7.1
GND.2: U$3.J2.4 (GND.2)
unnamed: U1.35 (TXD0), X3.3
unnamed: JP2.12, RN3.2, U1.37 (IO23)
unnamed: R11.2, X6.2
unnamed: JP1.2, X1.8 (F)
unnamed: U1.27 (IO16), X4.2
unnamed: JP2.10, RN3.3, U1.3 (SENSOR_VP)
unnamed: JP2.8, RN3.4, U1.4 (SENSOR_VN)
unnamed: JP2.6, RN3.5, U1.31 (IO19)
unnamed: U1.26 (IO4), X5.3
unnamed: U1.24 (IO2), X5.2
unnamed: R11.1, U1.23 (IO15)
unnamed: Q6.2 (B), R10.1
unnamed: JP2.4, RN3.6, U1.30 (IO18)
unnamed: Q6.1 (E), SG1.+
unnamed: JP8.2, X1.15 (F)
unnamed: R1.2, X7.2
unnamed: JP2.2, RN3.7, U1.29 (IO5)
unnamed: OK6.4 (COL), R28.2, U1.6 (IO35)
unnamed: OK20.4 (COL), R16.2, U1.7 (IO32)
unnamed: OK8.4 (COL), R4.2, U1.8 (IO33)
unnamed: OK22.4 (COL), R18.2, U1.9 (IO25)
unnamed: OK10.4 (COL), R6.2, U1.10 (IO26)
unnamed: OK24.4 (COL), R20.2, U1.11 (IO27)
unnamed: U1.28 (IO17), X4.3
unnamed: OK12.4 (COL), R8.2, U1.12 (IO14)
unnamed: U1.33 (IO21), U$3.J1.4 (SDA.1), X2.3
unnamed: OK26.4 (COL), R23.2, U1.13 (IO12)
unnamed: U1.36 (IO22), U$3.J1.3 (SCL.1), X2.4
unnamed: R10.2, U1.15 (IO13)
unnamed: OK5.1 (A), R28.1
unnamed: OK5.3 (EMIT), Q2.2 (B)
unnamed: OK6.1 (A), R3.2
unnamed: JP1.1, Q2.1 (E)
unnamed: JP1.3, OK6.2 (C)
unnamed: JP9.2, X1.7 (F)
unnamed: OK7.1 (A), R4.1
unnamed: OK7.3 (EMIT), Q3.2 (B)
unnamed: OK8.1 (A), R5.2
unnamed: JP3.1, Q3.1 (E)
unnamed: JP3.3, OK8.2 (C)
unnamed: JP10.2, X1.6 (F)
unnamed: OK9.1 (A), R6.1
unnamed: OK9.3 (EMIT), Q4.2 (B)
unnamed: OK10.1 (A), R7.2
unnamed: U1.34 (RXD0), X3.2
unnamed: JP5.1, Q4.1 (E)
unnamed: JP5.3, OK10.2 (C)
unnamed: JP11.2, X1.5 (F)
unnamed: OK11.1 (A), R8.1
unnamed: OK11.3 (EMIT), Q5.2 (B)
unnamed: OK12.1 (A), R9.2
unnamed: JP6.1, Q5.1 (E)
unnamed: JP6.3, OK12.2 (C)
unnamed: OK18.4 (COL), R14.2, U1.5 (IO34)
unnamed: JP12.2, X1.4 (F)
unnamed: OK17.1 (A), R14.1
unnamed: OK17.3 (EMIT), Q7.2 (B)
unnamed: OK18.1 (A), R15.2
unnamed: JP8.1, Q7.1 (E)
unnamed: JP8.3, OK18.2 (C)
unnamed: JP6.2, X1.12 (F)
unnamed: OK19.1 (A), R16.1
unnamed: OK19.3 (EMIT), Q8.2 (B)
unnamed: OK20.1 (A), R17.2
unnamed: JP9.1, Q8.1 (E)
unnamed: JP9.3, OK20.2 (C)
unnamed: JP5.2, X1.13 (F)
unnamed: OK21.1 (A), R18.1
unnamed: OK21.3 (EMIT), Q9.2 (B)
unnamed: OK22.1 (A), R19.2
unnamed: JP10.1, Q9.1 (E)
unnamed: JP10.3, OK22.2 (C)
unnamed: JP3.2, X1.14 (F)
unnamed: OK23.1 (A), R20.1
unnamed: OK23.3 (EMIT), Q10.2 (B)
unnamed: OK24.1 (A), R22.2
unnamed: JP11.1, Q10.1 (E)
unnamed: JP11.3, OK24.2 (C)
unnamed: OK25.1 (A), R23.1
unnamed: OK25.3 (EMIT), Q11.2 (B)
unnamed: OK26.1 (A), R24.2
unnamed: JP12.1, Q11.1 (E)
unnamed: JP12.3, OK26.2 (C)
VCC.2: U$3.J2.3 (VCC.2)

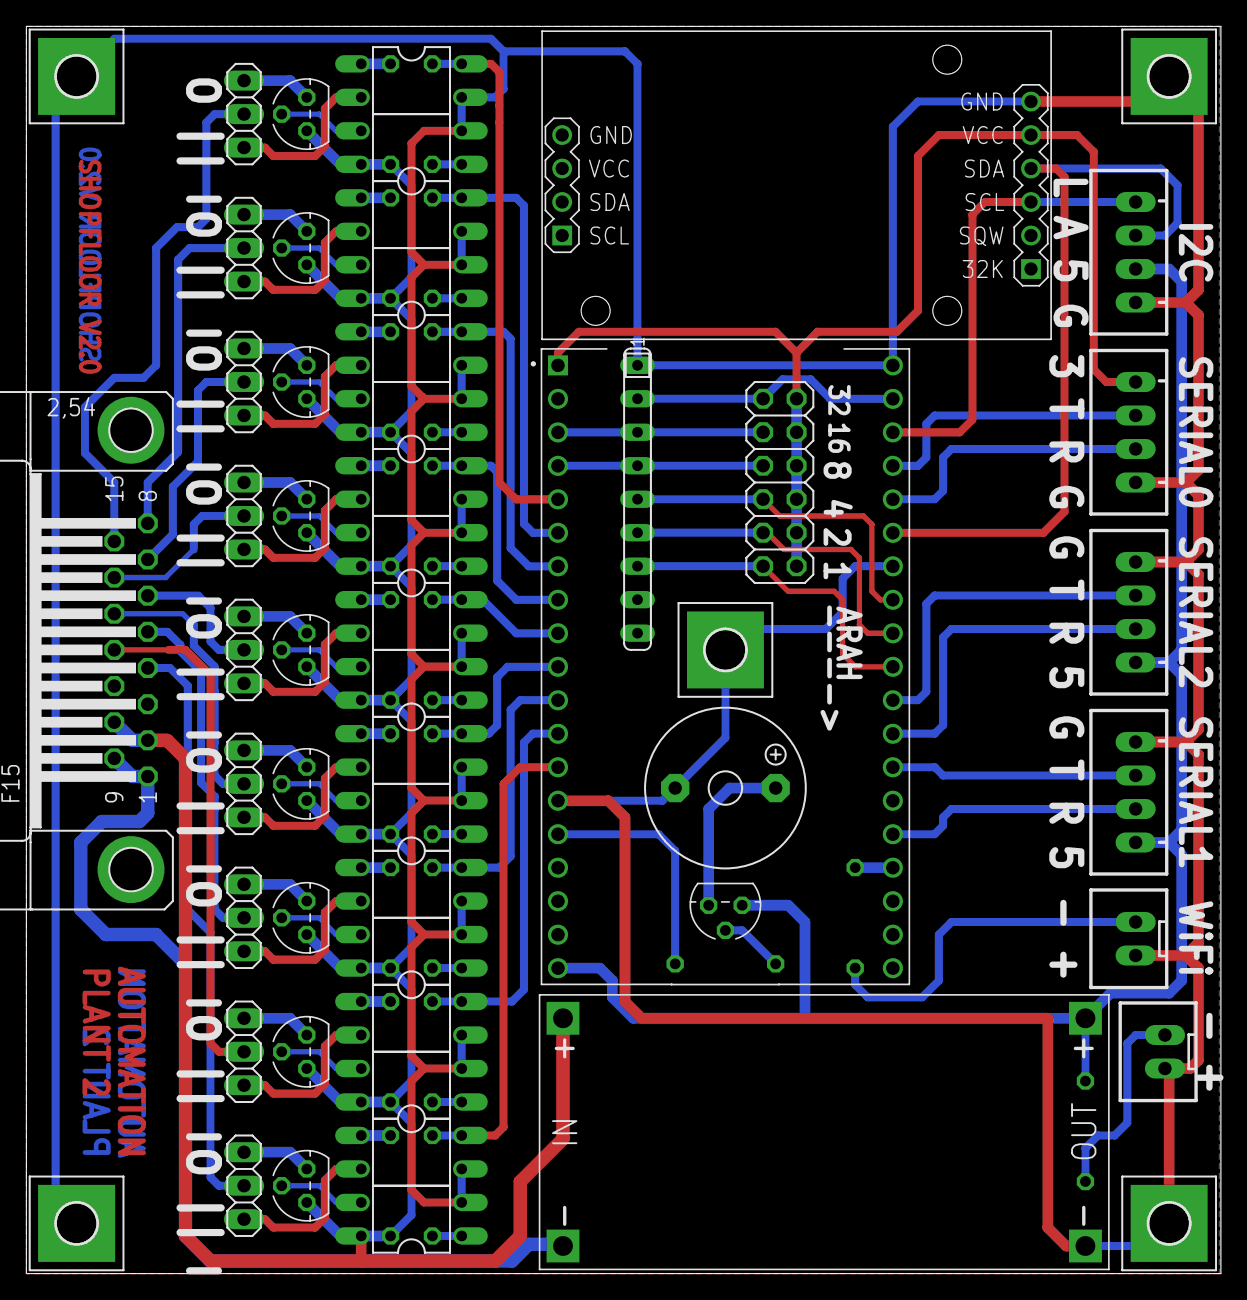
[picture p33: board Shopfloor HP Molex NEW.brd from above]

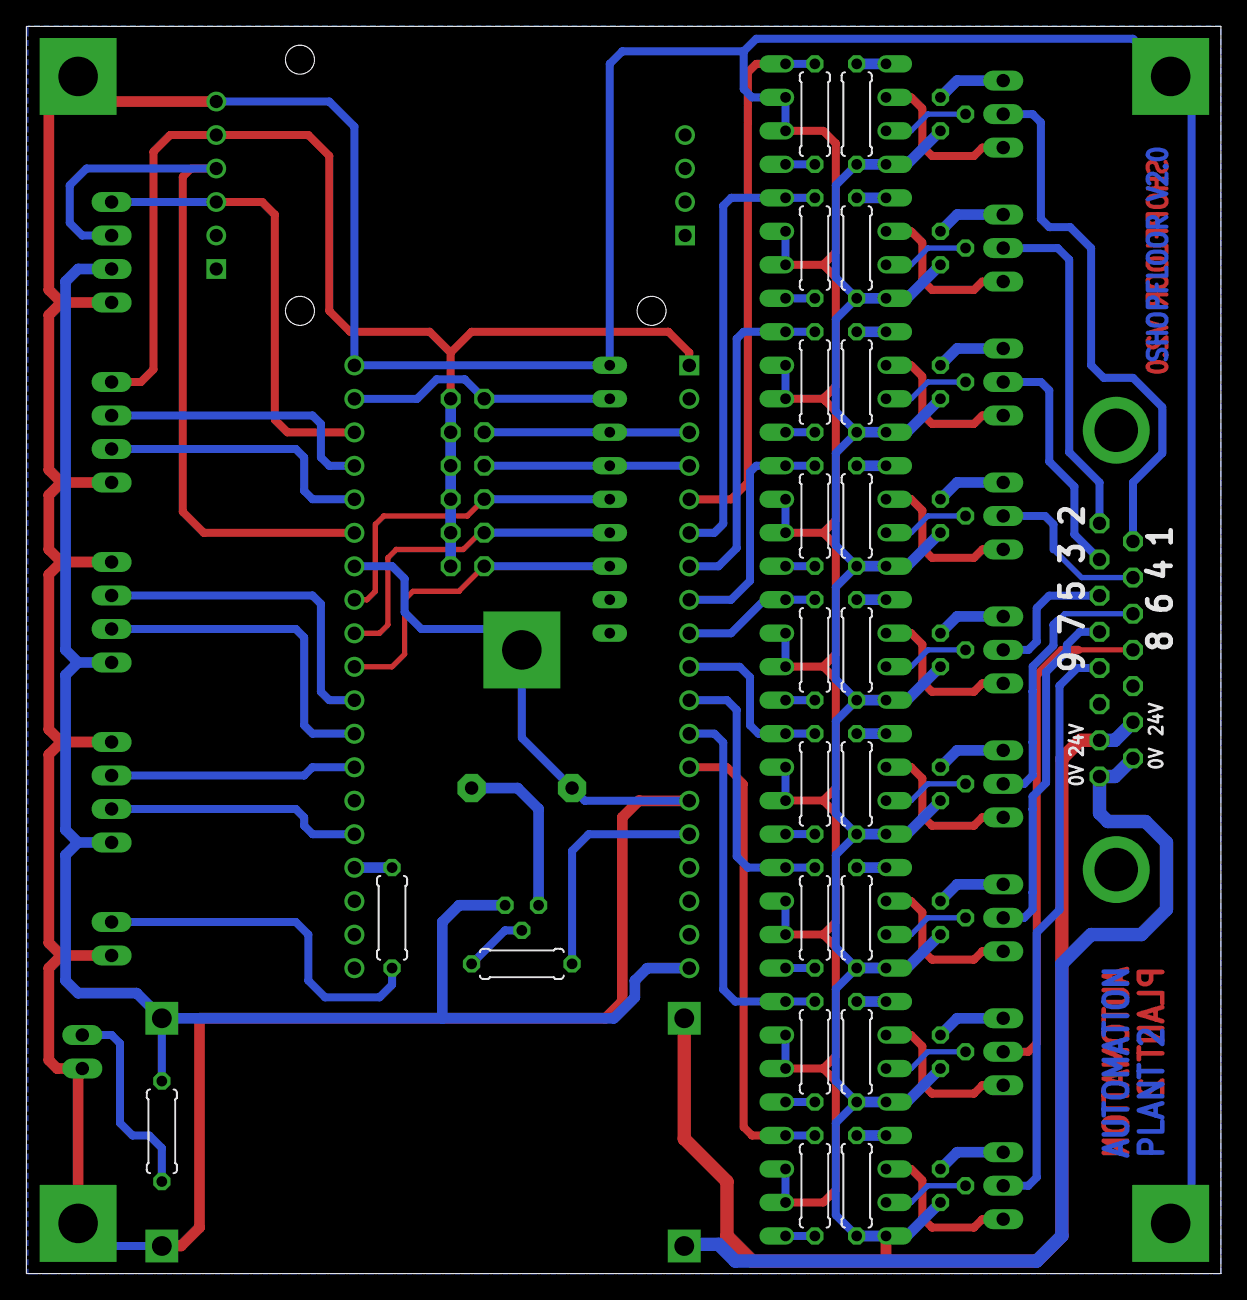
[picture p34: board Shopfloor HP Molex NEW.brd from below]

Board: 2 copper layers, 90.6 x 94.6 mm, 76 parts (21 on the bottom side), 88 nets.

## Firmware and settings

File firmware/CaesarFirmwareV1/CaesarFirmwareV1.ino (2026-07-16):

#include "config.h"
#include "Nextion.h"
#include <WiFi.h>
#include <PubSubClient.h>
#include <ArduinoJson.h>

WiFiClient espClient;
PubSubClient mqttClient(espClient);
char cycleStartTime[32] = "";
char cycleFinishTime[32] = "";

struct LayerComponents {
  const char* cycle;
  const char* output;
  const char* ok;
  const char* ng;
  const char* quota;
  const char* isi;
  const char* target;
  const char* model;
  const char* lot;
  const char* operatorName;
  const char* operatorId;
};

struct LayerState {
  uint32_t cycle;
  uint32_t output;
  uint32_t ok;
  uint32_t ng;
  uint32_t quota;
  uint32_t isi;
  uint32_t target;
  char model[32];
  char lot[32];
  char operatorName[32];
  uint32_t operatorId;
};

const uint8_t PAGE_DASHBOARD_ID = 0;
const uint8_t PAGE_LOGIN_F_ID = 1;
const uint8_t PAGE_LOGIN_B_ID = 2;
const uint8_t PAGE_MLD_F_ID = 3;
const uint8_t PAGE_MLD_B_ID = 4;
const uint8_t PAGE_LOT_F_ID = 5;
const uint8_t PAGE_LOT_B_ID = 6;
const uint8_t PAGE_OUTPUT_NG_ID = 7;
const uint8_t PAGE_INPUT_NG_F_ID = 8;
const uint8_t PAGE_INPUT_NG_B_ID = 9;
const uint8_t PAGE_DT_F_ID = 10;
const uint8_t PAGE_DT_B_ID = 11;
const uint8_t PAGE_DT_INFO_F_ID = 12;
const uint8_t PAGE_DT_INFO_B_ID = 13;
const uint8_t PAGE_DT_MC_ID = 14;
const uint8_t PAGE_DT_MC_INFO_ID = 15;
const uint8_t PAGE_SIM_ID = 16;
const uint8_t PAGE_SYS_ID = 17;
const uint8_t PAGE_KEYBD_A_ID = 18;
const uint8_t PAGE_KEYBD_B_ID = 19;

uint8_t currentPageId = 0;

NexPage pageDashboard = NexPage(PAGE_DASHBOARD_ID, 0, "pageDashboard");
NexPage pageLoginF = NexPage(PAGE_LOGIN_F_ID, 0, "pageLoginF");
NexButton bOkF = NexButton(PAGE_LOGIN_F_ID, 2, "bOkF");
NexButton bLogoutF = NexButton(PAGE_LOGIN_F_ID, 3, "bLogoutF");
NexButton bBackF = NexButton(PAGE_LOGIN_F_ID, 4, "bBackF");
NexText tNameF = NexText(PAGE_LOGIN_F_ID, 7, "tNameF");
NexNumber nIdF = NexNumber(PAGE_LOGIN_F_ID, 9, "nIdF");

NexPage pageLoginB = NexPage(PAGE_LOGIN_B_ID, 0, "pageLoginB");
NexButton bOkB = NexButton(PAGE_LOGIN_B_ID, 2, "bOkB");
NexButton bLogoutB = NexButton(PAGE_LOGIN_B_ID, 3, "bLogoutB");
NexButton bBackB = NexButton(PAGE_LOGIN_B_ID, 4, "bBackB");
NexText tNameB = NexText(PAGE_LOGIN_B_ID, 7, "tNameB");
NexNumber nIdB = NexNumber(PAGE_LOGIN_B_ID, 9, "nIdB");

NexPage pageMldF = NexPage(PAGE_MLD_F_ID, 0, "pageMldF");
NexButton bClearMF = NexButton(PAGE_MLD_F_ID, 4, "bClearMF");
NexButton bOkMF = NexButton(PAGE_MLD_F_ID, 5, "bOkMF");
NexText tInMF = NexText(PAGE_MLD_F_ID, 10, "tInMF");
NexPage pageMldB = NexPage(PAGE_MLD_B_ID, 0, "pageMldB");
NexButton bClearMB = NexButton(PAGE_MLD_B_ID, 4, "bClearMB");
NexButton bOkMB = NexButton(PAGE_MLD_B_ID, 5, "bOkMB");
NexText tInMB = NexText(PAGE_MLD_B_ID, 10, "tInMB");
NexPage pageLotF = NexPage(PAGE_LOT_F_ID, 0, "pageLotF");
NexButton bClearLotF = NexButton(PAGE_LOT_F_ID, 5, "bClearF");
NexButton bOkLotF = NexButton(PAGE_LOT_F_ID, 6, "bOkF");
NexText tInLotF = NexText(PAGE_LOT_F_ID, 11, "tInF");
NexNumber nIsiLotF = NexNumber(PAGE_LOT_F_ID, 12, "nIsiLotF");
NexPage pageLotB = NexPage(PAGE_LOT_B_ID, 0, "pageLotB");
NexButton bClearLotB = NexButton(PAGE_LOT_B_ID, 5, "bClearB");
NexButton bOkLotB = NexButton(PAGE_LOT_B_ID, 6, "bOkB");
NexText tInLotB = NexText(PAGE_LOT_B_ID, 11, "tInB");
NexNumber nIsiLotB = NexNumber(PAGE_LOT_B_ID, 12, "nIsiLotB");
NexPage pageOutputNG = NexPage(PAGE_OUTPUT_NG_ID, 0, "pageOutputNG");
NexButton bOkNgF = NexButton(PAGE_OUTPUT_NG_ID, 5, "bOkNgF");
NexButton bOkNgB = NexButton(PAGE_OUTPUT_NG_ID, 17, "bOkNgB");
NexPage pageInputNGF = NexPage(PAGE_INPUT_NG_F_ID, 0, "pageInputNGF");
NexPage pageInputNGB = NexPage(PAGE_INPUT_NG_B_ID, 0, "pageInputNGB");
NexPage pageDtF = NexPage(PAGE_DT_F_ID, 0, "pageDtF");
NexButton bBackDtF = NexButton(PAGE_DT_F_ID, 2, "bBackDtF");
NexButton bBhnF = NexButton(PAGE_DT_F_ID, 3, "bBhnF");
NexButton bTggPnsF = NexButton(PAGE_DT_F_ID, 4, "bTggPnsF");
NexButton bMoffF = NexButton(PAGE_DT_F_ID, 5, "bMoffF");
NexButton bLbhPnsF = NexButton(PAGE_DT_F_ID, 6, "bLbhPnsF");
NexButton bKrgPnsF = NexButton(PAGE_DT_F_ID, 7, "bKrgPnsF");
NexButton bRunF = NexButton(PAGE_DT_F_ID, 8, "bRunF");
NexButton bTrialF = NexButton(PAGE_DT_F_ID, 9, "bTrialF");

NexPage pageDtB = NexPage(PAGE_DT_B_ID, 0, "pageDtB");
NexButton bBackDtB = NexButton(PAGE_DT_B_ID, 2, "bBackDtB");
NexButton bBhnB = NexButton(PAGE_DT_B_ID, 3, "bBhnB");
NexButton bTggPnsB = NexButton(PAGE_DT_B_ID, 4, "bTggPnsB");
NexButton bMoffB = NexButton(PAGE_DT_B_ID, 5, "bMoffB");
NexButton bLbhPnsB = NexButton(PAGE_DT_B_ID, 6, "bLbhPnsB");
NexButton bKrgPnsB = NexButton(PAGE_DT_B_ID, 7, "bKrgPnsB");
NexButton bRunB = NexButton(PAGE_DT_B_ID, 8, "bRunB");
NexButton bTrialB = NexButton(PAGE_DT_B_ID, 9, "bTrialB");

NexPage pageDtInfoF = NexPage(PAGE_DT_INFO_F_ID, 0, "pageDtInfoF");
NexPage pageDtInfoB = NexPage(PAGE_DT_INFO_B_ID, 0, "pageDtInfoB");
NexPage pageDtMc = NexPage(PAGE_DT_MC_ID, 0, "pageDtMc");
NexButton bBackMc = NexButton(PAGE_DT_MC_ID, 2, "bBackMc");
NexButton bGMldMc = NexButton(PAGE_DT_MC_ID, 3, "bGMldMc");
NexButton bCMldMc = NexButton(PAGE_DT_MC_ID, 4, "bCMldMc");
NexButton bTrMc = NexButton(PAGE_DT_MC_ID, 5, "bTrMc");
NexButton bTrTlMc = NexButton(PAGE_DT_MC_ID, 6, "bTrTlMc");
NexButton bSetMc = NexButton(PAGE_DT_MC_ID, 7, "bSetMc");
NexButton bPrevMc = NexButton(PAGE_DT_MC_ID, 8, "bPrevMc");
NexButton bOffMc = NexButton(PAGE_DT_MC_ID, 9, "bOffMc");
NexButton bRunMc = NexButton(PAGE_DT_MC_ID, 10, "bRunMc");
NexButton bOrisolMc = NexButton(PAGE_DT_MC_ID, 11, "bOrisolMc");

NexPage pageDtMcInfo = NexPage(PAGE_DT_MC_INFO_ID, 0, "pageDtMcInfo");
NexPage pageSim = NexPage(PAGE_SIM_ID, 0, "pageSim");
NexButton bAutoEnF = NexButton(PAGE_SIM_ID, 35, "bAutoEnF");
NexButton bAutoDisF = NexButton(PAGE_SIM_ID, 36, "bAutoDisF");
NexButton bAutoEnB = NexButton(PAGE_SIM_ID, 37, "bAutoEnB");
NexButton bAutoDisB = NexButton(PAGE_SIM_ID, 38, "bAutoDisB");
NexPage pageSys = NexPage(PAGE_SYS_ID, 0, "pageSys");
NexVariable nFCavSys = NexVariable(PAGE_SYS_ID, 12, "nFCav");
NexVariable nBCavSys = NexVariable(PAGE_SYS_ID, 15, "nBCav");
NexPage keybdA = NexPage(PAGE_KEYBD_A_ID, 0, "keybdA");
NexPage keybdB = NexPage(PAGE_KEYBD_B_ID, 0, "keybdB");

NexTouch* nex_listen_list[] = {
  &pageDashboard,
  &pageLoginF, &bOkF, &bLogoutF, &bBackF, &tNameF, &nIdF,
  &pageLoginB, &bOkB, &bLogoutB, &bBackB, &tNameB, &nIdB,
  &pageMldF, &bClearMF, &bOkMF, &tInMF,
  &pageMldB, &bClearMB, &bOkMB, &tInMB,
  &pageLotF, &bClearLotF, &bOkLotF, &tInLotF, &nIsiLotF,
  &pageLotB, &bClearLotB, &bOkLotB, &tInLotB, &nIsiLotB,
  &pageOutputNG, &bOkNgF, &bOkNgB, &pageInputNGF, &pageInputNGB,
  &pageDtF, &bBackDtF, &bBhnF, &bTggPnsF, &bMoffF, &bLbhPnsF, &bKrgPnsF, &bRunF, &bTrialF,
  &pageDtB, &bBackDtB, &bBhnB, &bTggPnsB, &bMoffB, &bLbhPnsB, &bKrgPnsB, &bRunB, &bTrialB,
  &pageDtInfoF, &pageDtInfoB,
  &pageDtMc, &bBackMc, &bGMldMc, &bCMldMc, &bTrMc, &bTrTlMc, &bSetMc, &bPrevMc, &bOffMc, &bRunMc, &bOrisolMc,
  &pageDtMcInfo, &pageSim, &bAutoEnF, &bAutoDisF, &bAutoEnB, &bAutoDisB, &pageSys,
  &keybdA, &keybdB,
  NULL
};

void registerLoginCallbacks();
void registerInputCallbacks();
void registerDowntimeCallbacks();
void registerSimulationCallbacks();
void handleScanner();
void updateSimulation();
void initTimeSource();
void syncTimeSource();
void updateTnow();
void initInterlock();
void setupWifi();
void setupMqtt();
void mqttLoop();
void publishBothLayers();
void publishEvent(const char* json);

void setup() {
  Serial.begin(115200);
  SCANNER_SERIAL.begin(SCANNER_BAUD, SERIAL_8N1, SCANNER_RX_PIN, SCANNER_TX_PIN);
  initTimeSource();
  initInterlock();
  registerLoginCallbacks();
  registerInputCallbacks();
  registerDowntimeCallbacks();
  registerSimulationCallbacks();
  setupWifi();
  setupMqtt();
}

void loop() {
  nexLoop(nex_listen_list);
  mqttLoop();
  syncTimeSource();
  handleScanner();
  updateTnow();
  updateSimulation();
}

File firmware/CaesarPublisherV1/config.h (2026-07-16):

#ifndef CAESAR_PUBLISHER_CONFIG_H
#define CAESAR_PUBLISHER_CONFIG_H

#define WIFI_SSID "TIMEO"
#define WIFI_PASS "1234Saja"
#define MQTT_SERVER "broker.hivemq.com"
#define MQTT_PORT 1883

#define MQTT_ADDR "91c21b8614cd"
#define MQTT_CLIENT_ID "CaesarPublisher/" MQTT_ADDR
#define CONTROL_TOPIC "CONTROL/IOTHP-BP/" MQTT_ADDR
#define START_TOPIC "start/IOTHP-BP/" MQTT_ADDR
#define FINISH_TOPIC "finish/IOTHP-BP/" MQTT_ADDR

#define NTP_SERVER "pool.ntp.org"
#define WIB_TIMEZONE "WIB-7"

#define FRONT_PIN 32
#define BACK_PIN 35
#define UP_PIN 33
#define DOWN_PIN 25
#define WIFI_LED_PIN 26

#define OTA_USERNAME "admin"
#define OTA_PASSWORD "123654789"

#endif

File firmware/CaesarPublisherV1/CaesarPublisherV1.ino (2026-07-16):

#include <ESP32HTTPUpdateServer.h>
#include <PubSubClient.h>
#include <WebServer.h>
#include <WiFi.h>
#include <time.h>

#include "config.h"

WiFiClient wifiClient;
PubSubClient mqttClient(wifiClient);
WebServer httpServer(80);
ESP32HTTPUpdateServer httpUpdater;

void setup() {
  Serial.begin(115200);

  pinMode(FRONT_PIN, INPUT);
  pinMode(BACK_PIN, INPUT);
  pinMode(UP_PIN, INPUT);
  pinMode(DOWN_PIN, INPUT);
  pinMode(WIFI_LED_PIN, OUTPUT);
  digitalWrite(WIFI_LED_PIN, LOW);

  initCycleInputs();
  initTime();
  setupWifi();
  setupMqtt();

  httpUpdater.setup(&httpServer, "/update", OTA_USERNAME, OTA_PASSWORD);
  httpServer.begin();
}

void loop() {
  mqttLoop();
  syncTime();
  httpServer.handleClient();
  updateCycleInputs();
}

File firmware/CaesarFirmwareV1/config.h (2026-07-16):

#ifndef CAESAR_CONFIG_H
#define CAESAR_CONFIG_H

#include <stddef.h>
#include <stdint.h>
#include <string.h>

#define SCANNER_SERIAL Serial2
#define SCANNER_RX_PIN 16
#define SCANNER_TX_PIN 17
#define SCANNER_BAUD 9600

#define WIFI_SSID "TIMEO"
#define WIFI_PASS "1234Saja"
#define MQTT_SERVER "broker.hivemq.com"
#define MQTT_PORT 1883

#define TIME_SOURCE_NTP 1
#define TIME_SOURCE_RTC 0

#if (TIME_SOURCE_NTP + TIME_SOURCE_RTC) != 1
#error "Select exactly one time source"
#endif

#if TIME_SOURCE_RTC
#include <Wire.h>
#include <RTClib.h>
#endif

#define NTP_SERVER "pool.ntp.org"
#define WIB_TIMEZONE "WIB-7"
#define MQTT_ADDR "91c21b8614cd"
#define MQTT_CLIENT_ID "IOTHP-BP/" MQTT_ADDR
#define CONTROL_TOPIC "CONTROL/IOTHP-BP/" MQTT_ADDR
#define FINISH_TOPIC "finish/IOTHP-BP/" MQTT_ADDR
#define DATA_A_TOPIC "dataA/IOTHP-BP/" MQTT_ADDR
#define DATA_B_TOPIC "dataB/IOTHP-BP/" MQTT_ADDR
#define EVENT_TOPIC "event/IOTHP-BP/" MQTT_ADDR

struct Operator {
  uint32_t id;
  const char* name;
};

static const Operator OPERATORS[] = {
  { 1111, "Budi Andianto" },
  { 2222, "Andi Saputra" },
  { 3333, "Siti Nurhaliza" }
};

static const size_t OPERATOR_COUNT = sizeof(OPERATORS) / sizeof(OPERATORS[0]);

inline const Operator* findOperator(uint32_t id) {
  for (size_t i = 0; i < OPERATOR_COUNT; i++) {
    if (OPERATORS[i].id == id) {
      return &OPERATORS[i];
    }
  }
  return nullptr;
}

struct Mould {
  const char* code;
  const char* model;
  uint8_t cavity;
};

static const Mould MOULDS[] = {
  { "1111", "MOULD A", 8 },
  { "2222", "MOULD B", 6 },
  { "3333", "MOULD C", 4 }
};

static const size_t MOULD_COUNT = sizeof(MOULDS) / sizeof(MOULDS[0]);

inline const Mould* findMould(const char* code) {
  for (size_t i = 0; i < MOULD_COUNT; i++) {
    if (strcmp(MOULDS[i].code, code) == 0) {
      return &MOULDS[i];
    }
  }
  return nullptr;
}

struct Lot {
  const char* code;
  const char* model;
  uint16_t target;
};

static const Lot LOTS[] = {
  { "1111", "DEP FUSO", 108 },
  { "2222", "VARIO125", 120 },
  { "3333", "GENIO", 96 }
};

static const size_t LOT_COUNT = sizeof(LOTS) / sizeof(LOTS[0]);

inline const Lot* findLot(const char* code) {
  for (size_t i = 0; i < LOT_COUNT; i++) {
    if (strcmp(LOTS[i].code, code) == 0) {
      return &LOTS[i];
    }
  }
  return nullptr;
}

#endif

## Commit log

2026-07-12 chore: backup remote files to backup/
    [Shopfloor HP Molex NEW.brd, Shopfloor HP Molex NEW.sch]
2026-07-12 Reorganize project assets into folders
    Move HMI, firmware, PCB, and document files into dedicated subdirectories and remove obsolete root-level duplicates.
    [Shopfloor HP Molex NEW.brd, Shopfloor HP Molex NEW.sch]
2026-07-12 chore(gitignore): track nextion tools and output directories
    Comment out ignore rules for nextion/Nextion2Text and
    nextion/output so the extraction tool and generated
    assets are version controlled in the repository.
2026-07-13 refactor(firmware): migrate legacy sketch to versioned Caesar builds
    Delete the obsolete SF_HP_BrakePad Arduino sources and stale
    CAESAR_6/CAESAR_9 HMI binaries, and add the new CaesarFirmwareV0
    and CaesarFirmwareV1 project directories.
2026-07-13 fix(nextion): guard SoftwareSerial for ESP32 and raise baud to 115200
    Drop the unconditional SoftwareSerial include and only pull it in
    when USE_SOFTWARE_SERIAL is defined and the target is not an ESP32,
    preventing build failures on ESP32 boards. Also bump the debug and
    Nextion serial baud rates from 9600 to 115200 for faster transfers.
2026-07-13 feat(firmware): add login module and initialize serial communication
    Introduce a dedicated login component (login.h/login.cpp) and wire its
    callbacks into the Nextion event loop. Initialize Serial and Serial2
    at 115200 baud in setup, and add config.h, arduino-rules.md, and a
    tests directory to scaffold the project structure.
2026-07-13 refactor(login): merge login module into Arduino sketch
    Consolidate the previously separated login.h/login.cpp into a single
    login.ino and inline the Nextion object declarations into the main
    sketch. Remove the now-obsolete login lookup unit test to align with
    the simplified single-sketch build layout.
2026-07-13 fix(firmware): align Nextion login page IDs with HMI layout
    Update PAGE_LOGIN_F_ID and PAGE_LOGIN_B_ID to match the actual
    page indices defined in the Nextion editor project. Also add a
    firmware README to document the sketch structure and build setup.
    [CaesarFirmwareV1.ino]
2026-07-13 feat(config): add selectable Nextion simulator and device serial mode
    Introduce NEXTION_MODE_SIMULATOR and NEXTION_MODE_DEVICE flags in
    config.h to choose the communication target at compile time. Route
    nexSerial to Serial for the simulator or Serial2 for hardware, and
    guard the Serial2 initialization accordingly. Document both modes
    in the firmware README.
2026-07-13 fix(lib): route nexSerial via library NexConfig mode flags
    The ITEADLIB Nextion .cpp files do not include the sketch config.h,
    so the previous nexSerial defines there had no effect. Move the
    simulator/device selection into NexConfig.h with its own mode
    macros and remove the ineffective defines from config.h. Disable
    debug serial in simulator mode to avoid clashing with the Nextion
    protocol on the ESP32 USB port. Document the matched-mode
    requirement in the firmware README.
    [config.h]
2026-07-13 feat(scanner): add GM67 barcode scanner integration
    Add GM67 scanner support over ESP32 Serial1 with configurable RX/TX
    pins and baud rate defined in config.h. Track the active Nextion login
    page through push callbacks so scanned operator IDs route to the
    correct front or back login and update the HMI. Poll the scanner each
    loop iteration and document wiring plus Nextion preinitialize events
    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
    [CaesarFirmwareV1.ino, config.h, login.ino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]
2026-07-13 refactor(config): simplify serial setup and move scanner to Serial2
    Remove the Nextion simulator/device mode selectors from config.h and
    NexConfig.h so the HMI always communicates over the ESP32 USB Serial.
    Reassign the GM67 scanner to Serial2 (GPIO16/17) through a new
    SCANNER_SERIAL macro and drop the per-mode Serial2.begin in setup.
    Disable ITEADLIB debug serial by default and update the firmware
    README to reflect the new fixed serial assignments.
    [CaesarFirmwareV1.ino, config.h, scanner.ino]
2026-07-13 feat(scanner): reflect scanned id on Nextion login numeric fields
    Set the nIdF and nIdB numeric components to the scanned operator id
    on the front and back login pages so the value is shown on the
    display. Also correct the scanner model name from GM67 to GM66 in
    the documentation.
    [config.h, scanner.ino]
2026-07-13 refactor(config): widen operator id type to 32-bit
    Replace uint16_t with uint32_t for operator identifiers and update
    findOperator accordingly. Parse scanned input with strtoul instead
    of atoi to avoid truncation of large ids, and add a fallback that
    reflects the raw id on the numeric fields with a "PAGE?" label when
    the current page is not a recognized login page.
    [config.h, login.ino, scanner.ino]
2026-07-13 refactor(firmware): unify Nextion page tracking with single pop callback
    Replace the separate per-login-page push callbacks with a generic
    pageCallback attached via attachPop on every NexPage object. Track
    all HMI pages (dashboard, MLD, LOT, NG, DT, SIM, SYS, keyboard) by
    passing the page id pointer, and document the Preinitialize printh
    events for each page in the README.
    [CaesarFirmwareV1.ino, login.ino]
2026-07-13 fix(hmi): assign distinct printh page ids to every Nextion page
    Renumber the Preinitialize printh page identifier bytes so each HMI
    page emits a unique id. Pages that previously sent no id (dashboard,
    MLD, LOT, SIM, SYS) now report one, and pages that shared ids (DT,
    NG, input) receive dedicated values (0x03-0x17) to match the
    firmware's unified page tracking.
2026-07-13 feat(firmware): add downtime button handling and page callbacks
    Declare NexButton objects for the front, back, and machine downtime
    pages, register them in the Nextion listen list, and invoke
    registerDowntimeCallbacks() during setup. The new downtime.ino
    module manages downtime state through pageSys fields and page
    navigation. README documents the flow and required HMI edits.
2026-07-13 feat(rtc): integrate DS3231 module for live system clock
    Add rtc.ino with initRtc() and updateTnow() to read the DS3231
    over I2C via RTClib and refresh pageSys.tNow.txt every second.
    Include Wire and RTClib in config.h and document the RTC wiring
    and time format in the README.
2026-07-13 fix(rtc): gracefully handle RTC startup failures and power loss
    Return early with rtcReady disabled when the DS3231 fails to
    initialize over I2C. If the module reports lost power, set the
    clock to the firmware build time so timestamps remain valid.
    [rtc.ino]
2026-07-15 chore(hmi): remove obsolete HMI pages and backup artifacts
    Remove legacy HMI page binaries and the entire backup directory
    containing outdated project snapshots, sketches, and documentation
    to clean up the repository.
    [Shopfloor HP Molex NEW.brd, Shopfloor HP Molex NEW.sch]
2026-07-15 refactor(hmi): remove downtime trigger events and auto-popup logic
    Strip touch release handlers from downtime buttons on front, back,
    and machine pages so they no longer start downtime or navigate away.
    Also drop the dashboard auto-open downtime info block and adjust
    font IDs on info and lot/mould text components for consistency.
2026-07-15 feat(scanner): add mould and lot barcode scanning support
    Process scanned barcodes on front/back mould and lot pages to
    auto-fill HMI fields with model, cavity, target, and isi values
    from predefined lookup tables. Lot scans use the corresponding
    mould cavity count as the default isi when available.
2026-07-15 chore(config): replace mould barcode identifiers with numeric codes
    Update the predefined MOULDS lookup table to use simple numeric
    barcode values (1111, 2222, 3333) instead of alphanumeric ones
    and sync the scanner documentation accordingly.
    [config.h]
2026-07-15 feat(hmi): add manual confirmation flow for mould and lot input
    Decouple scanning from saving by having the scanner only fill the
    input fields, then requiring the operator to press OK to validate
    and persist mould/lot data. Register clear and confirm button
    callbacks for the front/back mould and lot pages and document the
    required Nextion Touch Release event changes in the README.
2026-07-15 refactor(hmi): strip inline touch logic from mould and lot buttons
    Strip the Touch Release event handlers from the clear and OK buttons
    on the front/back mould and lot pages. Validation and reset logic is
    now delegated to the host controller instead of being embedded in
    the Nextion HMI events.
2026-07-15 feat(input): add raw serial reader for Nextion text components
    Introduce readNextionText() which issues a get command and parses the
    0x70 header with 0xFF terminators from the serial stream. The mould
    and lot handlers now call this instead of the Nextion library's
    getText(), giving the firmware explicit control over parsing and a
    200ms read timeout.
    [input.ino]
2026-07-15 feat(input): add raw serial reader for Nextion numeric values
    Introduce readNextionValue to parse .val responses from Nextion
    components over the serial link, replacing the library's getValue
    calls in handleFrontLot and handleBackLot. Add error handling for
    failed reads and defer UI updates until inputs are validated.
    [input.ino]
2026-07-15 docs(readme): rewrite project and firmware docs in English
    Replace the Indonesian extraction-focused README with an English overview
    of the Caesar control system, its repository layout, and the HMI
    extraction workflow. Expand the firmware README with source file
    responsibilities, dependencies, and wiring details so contributors can
    understand the ESP32 architecture without reading the sketch code.
2026-07-15 feat(firmware): implement simulation mode with auto enable/disable controls
    Add four touch buttons for automatic enable/disable of front and back
    cavities on the simulation page, register their event callbacks, and
    invoke updateSimulation from the main loop. Simulation logic is placed
    in the new simulation.ino module.
2026-07-15 feat(hmi): reflect simulation metrics on dashboard displays
    Add updateFrontDashboardDisplay and updateBackDashboardDisplay to
    push cycle, output, and ISI values to the dashboard page during
    automatic front and back cavity cycles so operators can monitor
    live simulation results without switching to the sim page.
2026-07-16 fix(firmware): lock interlock when showing downtime info
    [downtime.ino]
2026-07-16 feat(firmware): integrate wifi, mqtt and cycle tracking
    Add WiFi and MQTT connectivity to the Caesar firmware along with a
    cycle update routine. Configuration for network credentials, broker
    address and control topic is defined in config.h, and the new
    wifi_mqtt.ino and cycle.ino modules are wired into setup/loop.
    [CaesarFirmwareV1.ino, config.h, cycle.ino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]
2026-07-16 feat(dashboard): sync live state across HMI events and add page
    Add dashboard.ino with updateDashboardStatus and invoke it from input,
    login, downtime, cycle and simulation handlers so operator, mould, lot
    and downtime changes refresh the dashboard and simulation displays in
    real time. Also sync simulation targets when entering the sim page.
2026-07-16 refactor(cycle): drive cycle update from MQTT finish event
    Replace the 250ms polling loop in updateCycle with an event-driven
    handler triggered by the FINISH_TOPIC "1cycle" message. Subscribe to
    the new finish topic in the MQTT client and drop the per-loop call so
    cycle metrics are refreshed only when the machine signals completion.
    [CaesarFirmwareV1.ino, config.h, cycle.ino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]
2026-07-16 feat(hmi): add CAESAR_15 design and migrate to cloud MQTT broker
    Replace the CAESAR_14 HMI project assets with the new
    CAESAR_15 design. Update firmware config and MQTT simulator
    to use the public broker.hivemq.com with device address
    be57077be216, and increase simulator cycle interval to 10s.
    [config.h]
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2026-07-16 refactor(firmware): centralize MQTT client and layer state definitions
    Move the WiFi/PubSubClient includes and the LayerComponents and
    LayerState struct declarations from publish.ino and wifi_mqtt.ino
    into the main sketch to avoid duplicate definitions and share
    state across modules.
    [CaesarFirmwareV1.ino, publish.ino, wifi_mqtt.ino]
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2026-07-16 fix(tools): set absolute Windows path for Node-RED SQLite database
    Replace the relative caesar.db reference in the debug subscriber
    flow with a hardcoded absolute path under the Brainless user profile
    and update README guidance. Users on other accounts must edit the
    sqlitedb config node to substitute their own account name.
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2026-07-16 fix(firmware): show ok count on dashboard instead of duplicate output
    Pass the ok (good) count to the dashboard display functions and
    render it in the secondary output field instead of repeating the
    total output value.
    [cycle.ino, simulation.ino]
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2026-07-16 refactor(firmware): generalize time handling for NTP and RTC sources
    Replace RTC-specific routines with a source-agnostic interface
    (initTimeSource/syncTimeSource/getCurrentTimestamp) and scope the
    RTClib includes to TIME_SOURCE_RTC so either clock backend compiles
    without unused dependencies.
    [CaesarFirmwareV1.ino, config.h, rtc.ino]
2026-07-16 feat(telemetry): include operator id in published cycle data
    Add an operatorId field to the layer state structs and Nextion
    component mappings so the operator identifier is read from the
    HMI and forwarded over MQTT as operator_id. Update the debug
    subscribers (Node.js and Node-RED) to persist the new field,
    including a schema migration that adds the column if missing.
    [CaesarFirmwareV1.ino, publish.ino]
2026-07-16 fix(downtime): extend HMI settle delays in showDowntimeInfo
    Increase the page transition delay from 100ms to 200ms and add a
    100ms delay after locking the interlock so the dashboard page is
    ready before downtime text is sent.
    [downtime.ino]
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2026-07-17 fix(firmware): route downtime back buttons to info pages
    Replace the direct dashboard navigation in the downtime back callbacks
    with showDowntimeInfo calls so users return to the relevant downtime
    info page instead of always landing on the main dashboard.
    [downtime.ino]

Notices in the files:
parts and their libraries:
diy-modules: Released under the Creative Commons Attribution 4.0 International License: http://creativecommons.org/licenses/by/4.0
